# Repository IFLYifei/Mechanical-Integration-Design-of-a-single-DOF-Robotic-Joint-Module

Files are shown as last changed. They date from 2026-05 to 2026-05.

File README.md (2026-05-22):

# Mechanical-Integration-Design-of-a-single-DOF-Robotic-Joint-Module

Mechanical integration design of a single-DOF robotic joint actuator module, including component selection, coaxial packaging, 3D CAD assembly, interface matching, structural verification, and documentation.

## License and Commercial Component Notes

This repository is provided as a personal portfolio and documentation project for the mechanical integration design of a single-DOF robotic joint module.

Commercial components used in the design, including the motor, harmonic reducer, encoder, and driver, are not self-developed components. Product names and model numbers are used only for component identification and compatibility description.

The original SolidWorks files of the motor and harmonic reducer are not included or redistributed in this repository. The encoder and driver models shown in the assembly are simplified envelope models created only according to their basic dimensional information, and are used for layout, space checking, and interface illustration.

These simplified models are not official supplier CAD models and should not be used as manufacturing references.

Unless otherwise stated, the original design documents, drawings, images, and self-designed CAD parts in this repository are created by the author and may be used for reference, modification, manufacturing, or integration into other projects.

No warranty, guarantee of engineering validity, or responsibility for manufacturing results is provided. Users should independently verify dimensions, strength, tolerances, materials, assembly feasibility, and compatibility before any practical application.

## Repository Structure

- `docs/`: Chinese design report
- `drawing/`: assembly and key part drawings
- `images/`: overview, assembly, and exploded-view figures
- `cad/custom-parts/`: self-designed SolidWorks part files
- `cad/simplified-commercial-components/`: simplified envelope models of commercial components

## Project Overview

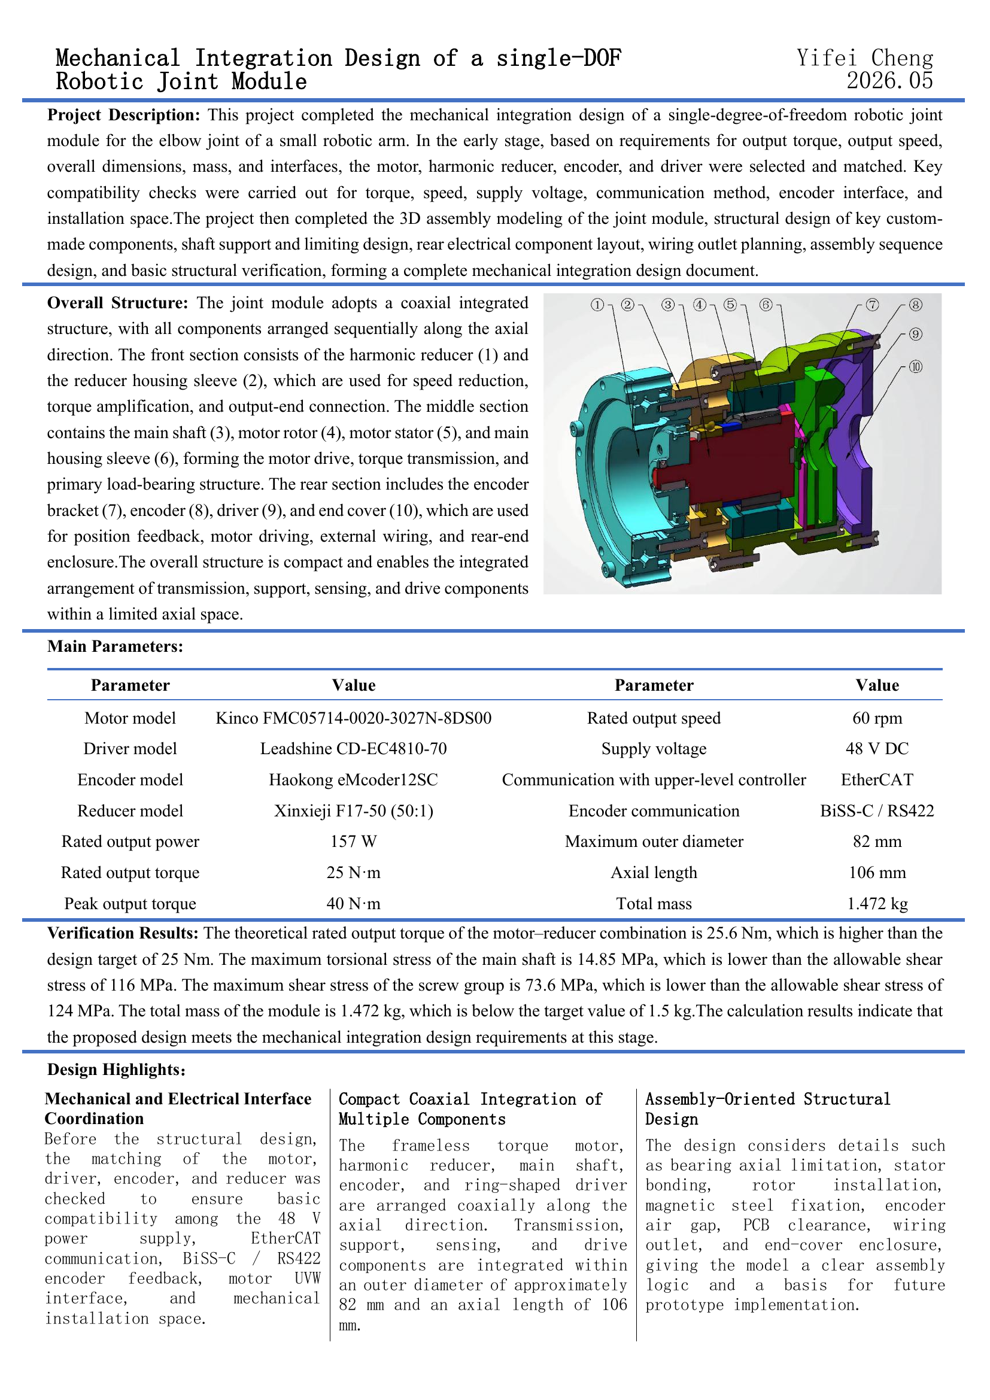
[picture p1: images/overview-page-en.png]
Project Overview


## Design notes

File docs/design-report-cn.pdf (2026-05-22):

# 单自由度机器人关节模组设计说明书

# 程一飞

2026 年 5 月

目录

## 1 项目概述

### 1.1 项目背景

随着协作机器人、小型机械臂和移动机器人等设备的发展，机器人关节模组

逐渐向高集成度、小型化和模块化方向发展。相比传统分散式结构，集成式关节

模组通常需要在有限空间内同时布置电机、减速器、轴承、编码器、驱动器和外

部安装接口，对结构紧凑性、装配可行性和接口布置提出了较高要求。

本项目面向小型机械臂关节应用，设计一种单自由度机器人关节模组。通过

对无框力矩电机、谐波减速器、编码器和驱动器等部件进行集成布置，为后续样

机制造、控制调试和系统应用提供机械结构基础。

### 1.2 项目目标

本项目目标是完成一种单自由度机器人关节模组的机械集成设计，形成结构

紧凑、装配可行、接口明确的关节模组方案。

具体目标包括：完成模组总体结构布局，确定电机、减速器、编码器、驱动

器 PCB 和轴承支撑结构的相对位置；完成关键零部件建模和外购件匹配；设计

外部安装接口、输出接口和内部连接结构；检查主要装配关系、线束空间和结构

干涉问题。

### 1.3 设计内容与项目边界

本项目的设计内容主要包括需求定义、负载扭矩估算、电机与减速器选型匹

配、编码器安装结构设计、定子固定结构设计、转子支撑结构设计、减速器安装

接口设计、输出法兰设计、轴承支撑设计、壳体与端盖设计、线束路径设计、散

热路径设计、机械限位设计以及整机装配结构设计。

项目成果包括三维总成模型、关键零件模型、装配关系、主要接口布置、基

础结构校核、零部件清单和设计说明文件。设计过程中主要关注机械结构集成、

外购件安装兼容性、装配顺序、线束布置空间和后续维护便利性。

本项目不涉及电机电磁设计、减速器内部齿形设计、控制器 PCB 设计、FOC

控制算法开发、EtherCAT 通信协议开发、上位机软件开发和嵌入式固件开发。

电机、减速器、编码器和驱动器均作为外购件处理。本阶段也不进行样机制造、

实验测试，以及完整的热仿真和强度仿真验证。

## 2 设计需求

### 2.1 应用场景

本项目设计的关节模组主要用于小型机械臂的肘关节，实现前臂相对于上臂

的俯仰转动。该位置需要承受前臂、末端执行器及负载产生的弯矩和惯性载荷，

因此对输出转矩、结构刚度和连接可靠性有一定要求。

模组一侧与上臂连杆连接，另一侧与前臂连杆连接，作为机械臂中部的动力

与支撑单元。

### 2.2 主要技术指标

本项目关节模组的主要技术指标如表 2-1 所示。

表 2-1 主要技术指标

指标项目 | 设计目标
关节类型 | 单自由度旋转关节
应用位置 | 小型机械臂肘关节
额定输出转矩 | 25 N·m
峰值输出转矩 | 40 N·m
额定输出转速 | 60 rpm
传动比 | 50:1
供电电压 | 48 V DC
最大外径 | 约 80 mm
轴向长度 | 约 100 mm
整机质量 | 目标不超过 1.5 kg
位置反馈 | 绝对值编码器
编码器通信 | BiSS-C / RS422
上位机通信 | CANopen / EtherCAT

上述指标用于指导电机、减速器、编码器、驱动器及机械结构的选型与集成

设计，后续具体参数以实际外购件和三维模型统计结果为准。

### 2.3 结构设计要求

关节模组应采用同轴集成结构，使电机、减速器、主轴和编码器尽量沿同一

轴线布置，以保证结构紧凑和传动稳定。

壳体结构应能够完成电机定子、减速器、轴承和驱动器 PCB 的安装固定，

并为内部线束预留必要空间。输出端应设置可靠的连接接口，用于与机械臂前臂

连杆连接。

轴系结构应具备明确的轴向定位和径向支撑方式，轴承、挡圈、轴肩和紧固

件布置应满足装配和限位要求。各连接部位应预留合理的螺钉安装空间，避免装

配工具干涉。

整体结构应便于装配和拆卸，关键零部件之间应避免明显干涉，并尽量减少

不必要的复杂结构。

### 2.4 接口设计要求

关节模组应设置清晰的机械接口和电气接口。机械接口包括与上臂连杆连接

的固定接口，以及与前臂连杆连接的输出接口，接口处应具备定位和螺栓连接结

构，保证安装可靠。

电气接口主要包括驱动器电源接口、电机三相 UVW 接口、编码器接口和

上位机通信接口。各接口应布置在便于接线和维护的位置，并避免与轴承、减速

器、壳体和运动部件发生干涉。

接口设计应尽量采用常见规格，便于后续采购、装配和替换。

## 3 总体方案设计

### 3.1 模组总体结构方案

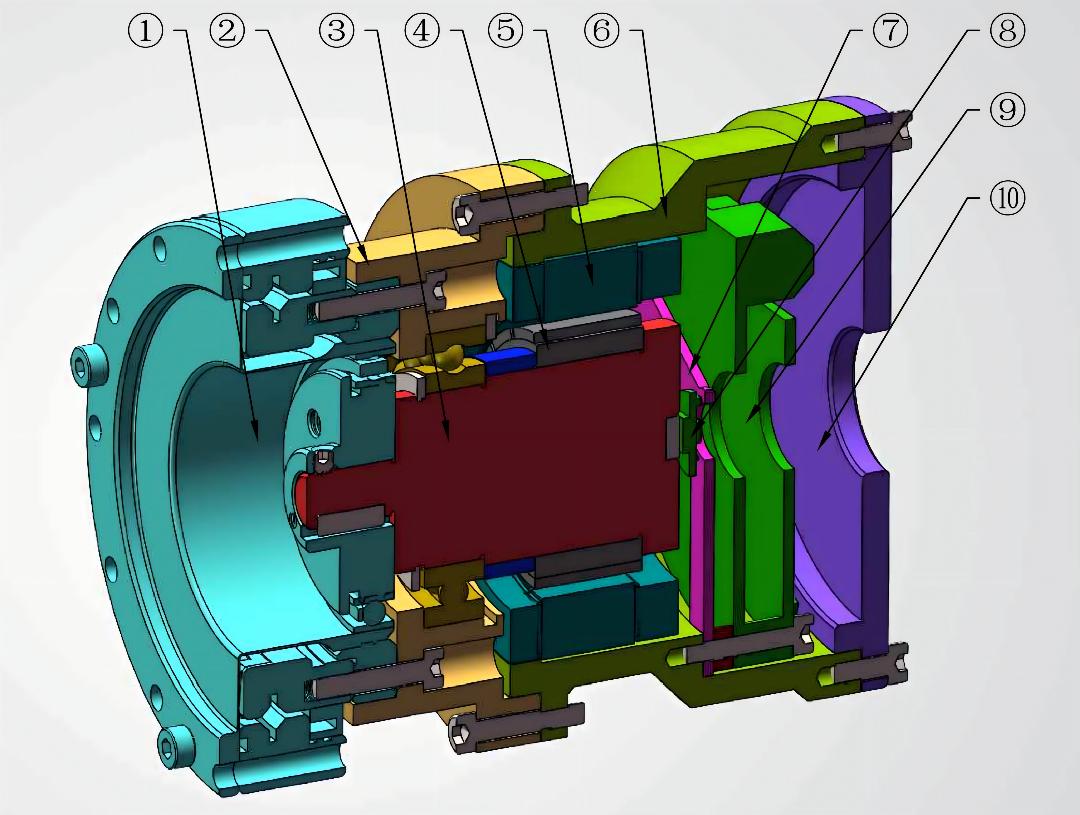
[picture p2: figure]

图 3-1 关节模组总体结构示意图

关节模组采用同轴集成结构，主要由谐波减速器（1）、减速器缸套（2）、

主轴（3）、电机转子（4）、电机定子（5）、主缸套（6）、编码器支架（7）、

编码器（8）、驱动器（9）和端盖（10）组成，如图 3-1 所示。

其中，谐波减速器作为外购传动部件安装在输出侧，减速器缸套和主缸套共

同构成主要承载壳体。电机转子与主轴连接，电机定子固定在主缸套内侧。编码

器通过编码器支架布置在后端，驱动器安装在模组后部空间内，端盖用于封闭和

固定后端结构。整体结构沿轴向紧凑布置，满足肘关节模组的机械集成需求。

### 3.2 传动方案

本模组采用“无框力矩电机 + 谐波减速器”的传动方案。电机定子固定在主

缸套内，电机转子与中心主轴连接，带动谐波减速器的波发生器旋转，作为减速

器的输入端。

谐波减速器由波发生器、柔轮和刚轮组成。本方案中，刚轮与减速器缸套固

定连接，作为固定端；波发生器与电机转子侧轴系连接，作为输入端；柔轮与输

出端连接，作为关节的输出端。电机转矩经波发生器输入后，通过柔轮与刚轮之

间的齿差啮合实现减速增扭，最终由柔轮侧输出至机械臂连杆。

该传动方案传动比大、结构紧凑，适合小型机械臂肘关节对输出转矩和安装

空间的要求。

### 3.3 支撑与定位方案

模组的支撑与定位主要围绕两条传力路径展开。

第一条为外部载荷传递路径。机械臂外部连杆分别与减速器柔轮输出侧接口

和主缸套/端盖后端固定接口连接，外部载荷通过两侧法兰传递至减速器缸套、

主缸套和端盖结构。减速器缸套与主缸套之间采用止口定位和螺栓连接，用于保

证壳体连接刚度和整体同轴性。

第二条为内部转矩传递路径。电机定子固定在主缸套内，电机转子带动主轴

及波发生器旋转，转矩经谐波减速器传递至柔轮输出端。主轴通过轴承支撑在壳

体内，用于承受轴系的径向载荷，并配合轴肩、轴用挡圈和孔用挡圈完成轴向限

位，避免轴承和轴系发生轴向窜动。

该方案通过壳体止口定位、螺栓连接、轴承支撑和挡圈限位，保证外部连接

结构与内部传动轴系具有明确的支撑和定位关系。

### 3.4 电气集成方案

模组后端设置驱动器安装空间，驱动器（9）布置在端盖（10）内侧，用于

连接电机、编码器和外部控制系统。电机三相线由电机定子区域引出后接入驱动

器，对应 UVW 三相接口。

编码器（8）安装在编码器支架（7）上，其信号线和供电线接入驱动器编码

器接口，用于关节位置反馈。驱动器还设置电源接口和通信接口，分别用于外部

48 V 供电和上位机通信。

线束主要集中在模组后端布置，避免穿过减速器输出侧和主要旋转部件区域。

该方案便于接线、维护和后续电气调试。

### 3.5 装配方案概述

模组装配按前端到后端的顺序进行。首先将谐波减速器与减速器缸套连接，

完成输出侧传动部件的初步定位；随后安装主轴、轴承、挡圈及相关轴系零件，

使轴系与减速器输入端建立连接。

之后将主缸套与电机定子组成一体，并与前端减速器缸套连接，完成电机定

子固定和壳体主体装配。电机转子与轴系连接后，形成从电机到谐波减速器的传

动路径。

最后在后端安装编码器支架、编码器、驱动器和端盖，并完成电机线、编码

器线和外部接口的连接。该装配顺序有利于先保证减速器和轴系定位，再完成电

机、电气部件和后端封闭结构的安装。

## 4 关键部件选型

### 4.1 电机选型

根据表 2-1 中的设计目标，关节模组额定输出转矩为 25 N·m，额定输出转

速为 60 rpm，供电电压为 48 V DC，传动比为 50:1。综合考虑转矩、转速、供

电电压和结构集成空间，本项目选用步科 FMC05714-0020-3027N-8DS00 无框

力矩电机作为驱动电机。

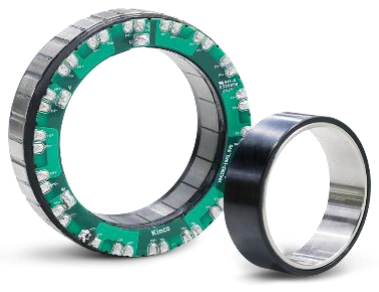
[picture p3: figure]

图 4-1 步科 FMC 系列某款无框力矩电机

按谐波减速器效率 80% 估算，电机侧所需额定转矩为：

Tm =

25
50 × 0.8

= 0.625 N⋅m

所选电机额定转矩为 0.64 N·m，高于计算所需的 0.625 N·m，能够满足额

定输出转矩要求。其额定转速为 3000 rpm，经过 50:1 减速后，理论输出转速

为：

nout =

3000
50 = 60 rpm

该结果与表 2-1 中的额定输出转速目标一致。电机额定功率为 200 W，额

定电压与 48 V 低压驱动系统匹配，适合用于小型机械臂肘关节模组。

所选电机在额定工况下的理论输出转矩为：

Tout = 0.64 × 50 × 0.8 = 25.6N⋅m

因此，该电机能够满足 25 N·m 额定输出转矩目标，并具有一定余量。对于

40 N·m 峰值输出转矩，电机侧所需峰值转矩约为 1 N·m，该工况由电机短时过

载能力和驱动器峰值电流共同承担，后续在 9.2 节中进行匹配校核。

### 4.2 驱动器选型

本项目选用雷赛 CD-EC4810-70 环形伺服驱动器作为电机驱动单元，如图

4-2 所示。该驱动器额定输入电压为 48 V DC ±10%，与本项目 48 V 低压供电

方案一致。

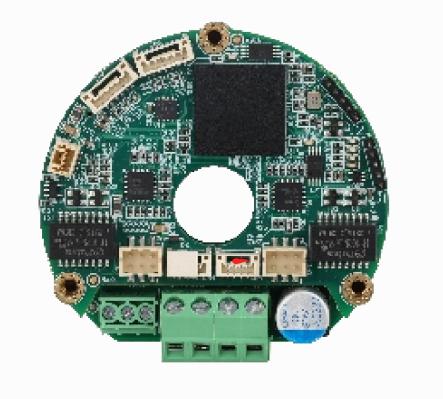
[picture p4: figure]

图 4-2 雷赛 CD-EC4810-70 环形伺服驱动器

该驱动器额定电流为 10 Arms，峰值电流为 30 Arms，连续功率为 256 W。

所选电机额定功率为 200 W，因此驱动器在功率和电流能力上能够满足电机驱

动需求，并具有一定余量。

在接口方面，该驱动器支持伺服电机三相输出、编码器接口和 EtherCAT 通

信接口。其中 EtherCAT 接口满足表 2-1 中对上位机通信方式的要求，可用于

后续与上位机或控制系统进行实时通信。

该驱动器外径为 Φ66 mm，内孔尺寸为 Φ15 mm，整体尺寸适合布置在关节

模组后端空间内，便于实现驱动器与电机、编码器及外部接口的集成。

### 4.3 编码器选型

本项目选用昊控 eMCoder 12SC 微型单圈绝对值编码器作为位置反馈元件，

如图 4-3 所示。该编码器直径为 12 mm，厚度为 2.8 mm，体积较小，适合布

置在关节模组后端有限空间内。

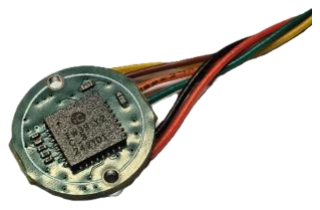
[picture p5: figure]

图 4-3 昊控 eMCoder 12SC 微型绝对值编码器

该编码器供电电压范围为 4.5–5.5 V DC，工作电流约 50 mA，与常见驱动

器编码器供电接口匹配。其单圈分辨率为 24 位，支持 BiSS-C 通信，物理层采

用 RS-422 差分信号，满足本项目对绝对值编码器和 BiSS-C / RS422 通信方式

的要求。

结构安装方面，编码器与磁钢配合使用，推荐磁芯与芯片间距为 0.5 mm，

安装同心度要求为 ±0.2 mm，磁铁水平度要求为 ±2°。因此在结构设计中需通过

编码器支架控制其安装位置和气隙，保证编码器能够稳定读取转子位置信号。

本方案仅采用电机侧编码器进行位置反馈，暂不设置输出端编码器和输出端

力矩传感器。

### 4.4 谐波减速器选型

根据表 2-1 中的设计目标，关节模组传动比为 50:1，额定输出转矩为 25

N·m，峰值输出转矩为 40 N·m。综合考虑输出转矩、结构尺寸和安装形式，本

项目选用鑫械技 F17-50 谐波减速器作为减速传动部件。

该减速器传动比为 50:1，质量约为 0.53 kg，背隙不大于 10 arcsec。根据厂

家参数，F17-50 的平均负载转矩容许最大值为 34 N·m，起动停止时容许峰值转

矩为 44 N·m，瞬间容许最大转矩为 91 N·m，能够满足本项目额定输出转矩和

峰值输出转矩要求。其润滑脂条件下容许平均输入转速为 3500 r/min，能够覆盖

电机 3000 r/min 的额定转速。

本方案中，波发生器作为输入端与电机转子侧轴系连接，刚轮与减速器缸套

固定，柔轮作为输出端与外部连杆连接，实现减速增扭输出。

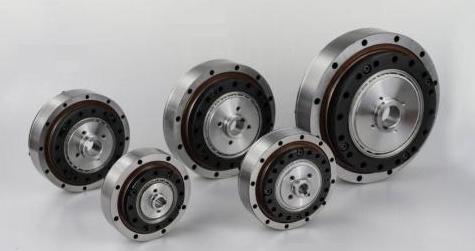
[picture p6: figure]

图 4-4 鑫械技 F 系列谐波减速器

### 4.5 轴承、挡圈与紧固件选型

本项目主轴支撑采用 61905 深沟球轴承。该轴承内径为 25 mm，外径为 42

mm，宽度为 9 mm，尺寸与主轴及减速器缸套轴承孔相匹配。轴承类型按 GB/T

276-2013 深沟球轴承外形尺寸标准选用。

轴向限位采用弹性挡圈结构。主轴上选用轴用弹性挡圈，规格 25，GB/T

894.1；减速器缸套轴承孔内选用孔用弹性挡圈，规格 42，GB/T 893.1。轴承内

圈通过轴肩和轴用挡圈限位，轴承外圈通过减速器缸套台阶和孔用挡圈限位，从

而限制轴系轴向窜动。

紧固件主要采用 GB/T 70.1-2008 内六角圆柱头螺钉。其中，谐波减速器与

减速器缸套连接采用 4 个 M3×16 螺钉；减速器缸套与主缸套连接采用 6 个

M3×16 螺钉；驱动器、编码器支架与主缸套连接采用 3 个 M3×16 螺钉；后端

盖连接采用 4 个 M3×8 螺钉。

输出端辅助固定采用 1 个 M3×3 内六角凹端紧定螺钉，标准为 GB/T

80-2007。主轴与相关连接件之间采用 A 型普通平键 3×3×10，标准为 GB/T

1096-2003，用于传递转矩并保证周向定位。

整体上，轴承、挡圈、螺钉、紧定螺钉和平键均采用常见国标件，便于采购、

装配和后续维护。

## 5 机械结构设计

### 5.1 外壳结构设计

模组外壳主要由减速器缸套、主缸套和端盖组成，如图 5-1 所示。减速器

缸套位于前端，用于安装外购谐波减速器，并对减速器刚轮进行定位和固定；主

缸套位于中部，是电机定子、轴系支撑和后端结构的主要安装基础；端盖位于后

端，用于封闭模组并形成后端连接结构。

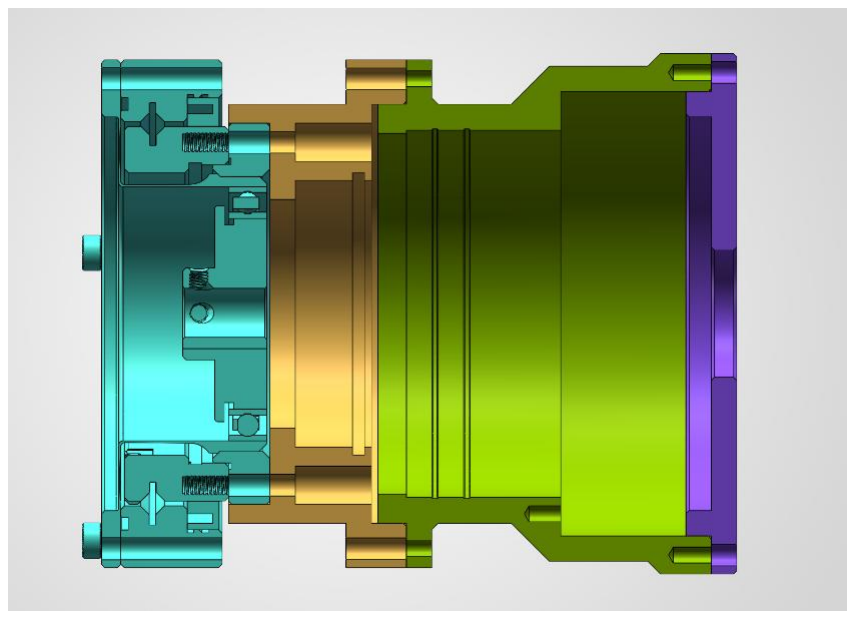
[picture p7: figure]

图 5-1 关节模组外壳结构剖视图

外部机械接口分布在模组左右两侧。左侧为减速器输出侧接口，由谐波减速

器柔轮输出端与前端连接法兰形成，用于连接机械臂前臂连杆；右侧为固定侧接

口，由端盖及主缸套后端法兰形成，用于连接机械臂上臂连杆。左右两侧接口共

同构成肘关节模组与外部连杆的主要连接结构，并承担外部载荷向模组壳体的传

递。

减速器缸套与主缸套之间采用止口定位和螺钉连接，以保证前端减速器与电

机轴系的同轴关系。主缸套内壁设置电机定子安装面，并在定子胶接区域布置两

道环形胶槽，用于储胶和提高定子与壳体之间的连接可靠性。

端盖通过螺钉与主缸套连接，用于固定后端结构并保护内部编码器和驱动器。

整体外壳采用分段式结构，便于减速器、轴系、电机和后端电气部件按顺序装配。

### 5.2 主轴结构设计

主轴结构如图 5-2 所示。该轴贯穿电机转子和谐波减速器输入端，是电机

转矩传递至减速器的主要轴系零件。

在减速器侧，波发生器内部带有减速器自带的柔性轴承，该轴承随波发生器

呈椭圆变形，用于使柔轮产生周期性弹性变形。该部分属于谐波减速器自身结构，

不作为本项目单独设计的支撑轴承。

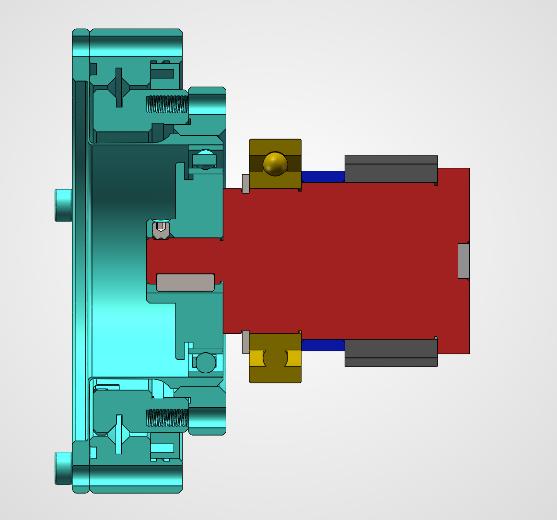
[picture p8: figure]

图 5-2 主轴及轴系结构示意图

在减速器缸套内，另设置一处 61905 深沟球轴承 对主轴进行支撑。轴承内

圈通过轴肩和轴用挡圈限位，轴承外圈通过缸套台阶和孔用挡圈限位，用于保证

轴系的径向支撑和轴向定位。

电机转子安装在主轴中部，采用过盈配合与主轴连接，以传递电机转矩。转

子左侧通过套杯结构定位，右侧通过主轴轴肩定位，从而限制转子轴向位置。

输出端设置 3×3×10 A 型平键 和紧定螺钉，用于输出连接件的周向定位和

辅助固定。整体轴系通过轴承支撑、挡圈限位、过盈配合和键连接，实现电机转

子到谐波减速器的稳定转矩传递。

### 5.3 电机安装结构设计

电机采用无框力矩电机结构，主要由电机定子和电机转子组成，如图 5-3 所

示。电机定子安装在主缸套内侧，通过主缸套内孔进行径向定位，并采用胶接方

式固定。为提高胶接可靠性，主缸套定子安装区域设置两道环形胶槽，用于储胶

并防止装配时胶层被完全挤出。

电机转子安装在主轴中部，通过过盈配合与主轴连接，实现转矩传递。转子

左侧由套杯结构进行轴向定位，右侧由主轴轴肩限位，从而确定转子在轴向上的

安装位置。

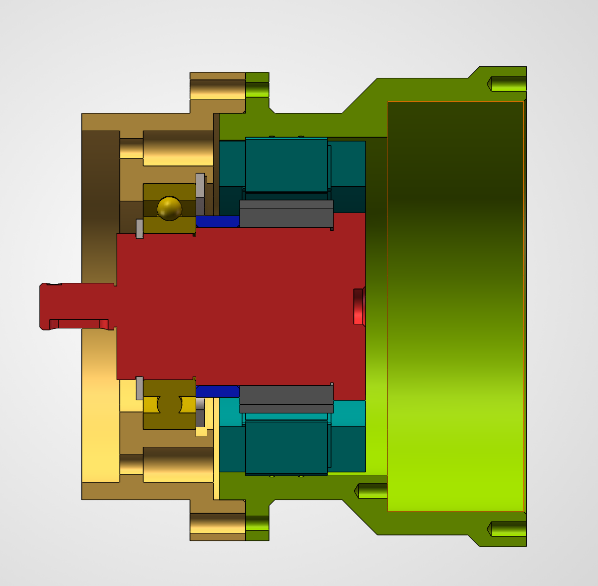
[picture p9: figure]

图 5-3 电机安装结构剖视图

电机整体布置在减速器与后端电气部件之间，定子外侧与主缸套接触，有利

于电机热量通过壳体向外传递。电机引出线从定子区域向后端驱动器方向布置，

避免经过减速器输出侧和主要旋转部件区域。

### 5.4 编码器安装结构设计

编码器安装结构如图 5-4 所示。编码器布置在电机后端，用于检测主轴及

电机转子的角位置信号。磁钢安装在主轴后端，与轴系同步旋转；编码器 PCB 固

定在编码器支架上，并与磁钢保持同轴布置。

编码器支架采用辐条式结构，三端与主缸套固定连接，中间环用于安装编码

器 PCB。该结构能够避开电机转子和后端驱动器空间，同时便于编码器与后端

驱动器的线路布置。

根据编码器安装要求，磁钢与芯片之间需保持约 0.5 mm 的工作气隙。设计

中通过编码器支架的安装面控制轴向距离，并通过主轴后端磁钢安装面保证磁钢

位置。该结构重点保证编码器气隙、同心度和装配可达性。

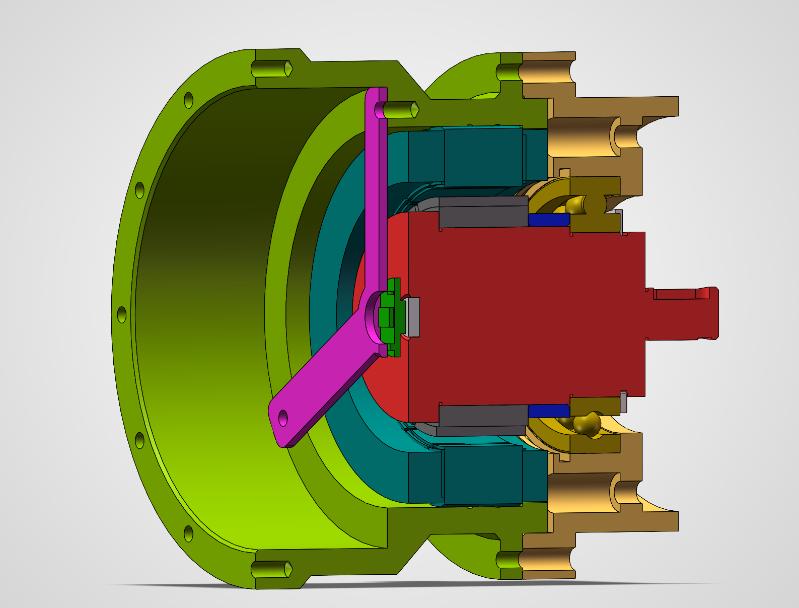
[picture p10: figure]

图 5-4 编码器安装结构示意图

### 5.5 PCB 与电气接口安装结构设计

驱动器 PCB 安装在模组后端空间内，如图 5-5 所示。PCB 通过安装结构

固定在主缸套后侧，并与端盖之间预留装配空间。PCB 中心设有通孔，用于避

让主轴后端和编码器安装区域。

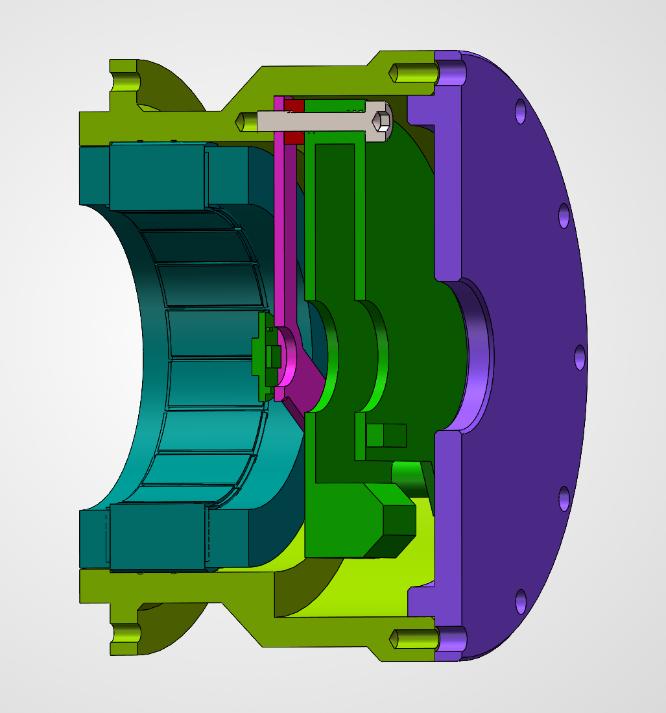
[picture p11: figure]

图 5-5 驱动器 PCB 与电气接口安装结构示意图

编码器支架布置在 PCB 前侧，编码器固定在支架端部，与主轴后端磁钢对

应布置。驱动器 PCB 与编码器支架、主缸套之间保持必要间隙，避免装配干涉。

电气接口集中布置在驱动器 PCB 上，包括电源接口、电机 UVW 接口、

编码器接口和上位机通信接口。端盖中心设置出线孔，用于外部接口线引出。具

体线束走向和空间检查在第 6 章中说明。

## 6 接口与布线设计

### 6.1 电源与通信接口

驱动器 PCB 的主要接口布置如图 6-1 所示。为便于结构建模和后续布线

说明，图中将接口简化为四类：编码器接口（1）、EtherCAT 通信接口（2）、

主回路电源接口（3）和电机 UVW 接口（4）。

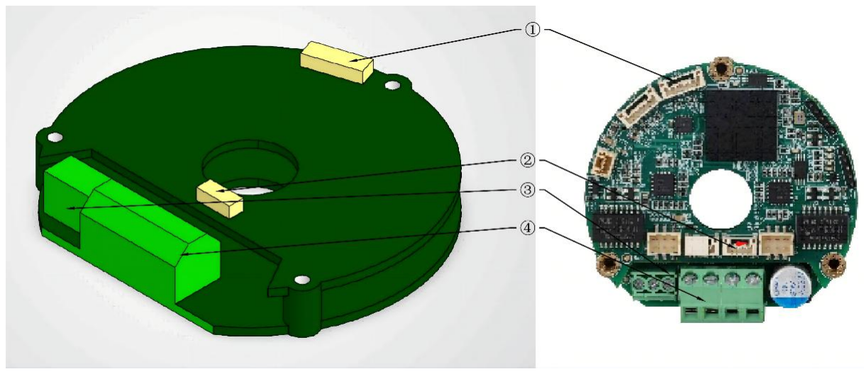
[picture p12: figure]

图 6-1 驱动器 PCB 接口布置示意图

其中，主回路电源接口（3）用于接入外部 48 V DC 电源，为驱动器和电机

驱动部分供电。该接口属于外部接口，设计中通过端盖中心孔引出电源线，与外

部供电系统连接。

EtherCAT 通信接口（2）用于驱动器与上位机或主控制器之间的数据通信，

实现控制指令下发和状态信息反馈。所选驱动器支持 EtherCAT 通信，满足本项

目对上位机通信接口的要求。

编码器接口（1）用于连接 eMCoder 12SC 绝对值编码器，信号形式为

BiSS-C / RS422，同时提供编码器供电。电机 UVW 接口（4）用于连接无框力

矩电机三相绕组。

### 6.2 电机与编码器接口

电机与编码器接口如图 6-2 所示。电机采用三相无框力矩电机，定子绕组

引出 U、V、W 三相线，并接入驱动器 PCB 上的电机 UVW 接口，用于实现

电机驱动。

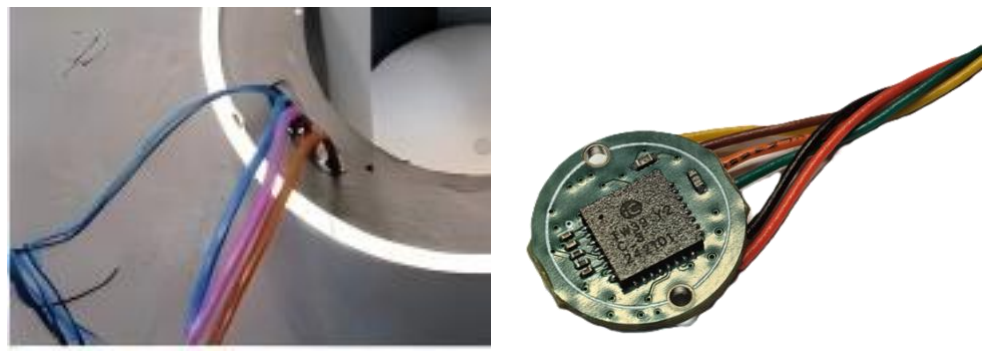
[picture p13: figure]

图 6-2 电机三相线与编码器接口示意图

编码器采用 eMCoder 12SC 单圈绝对值编码器，其引线包括 5 V 供电、0 V

地线、CLK+、CLK−、DATA+、DATA− 等信号线。编码器通过 BiSS-C / RS422

差分信号与驱动器连接，用于反馈电机侧转角位置。

本项目中，电机 UVW 线和编码器线均属于模组内部连接线，主要布置在

电机后端至驱动器 PCB 之间。接口位置集中在驱动器 PCB 附近，便于装配和

后续检查。

### 6.3 线束走向与空间检查

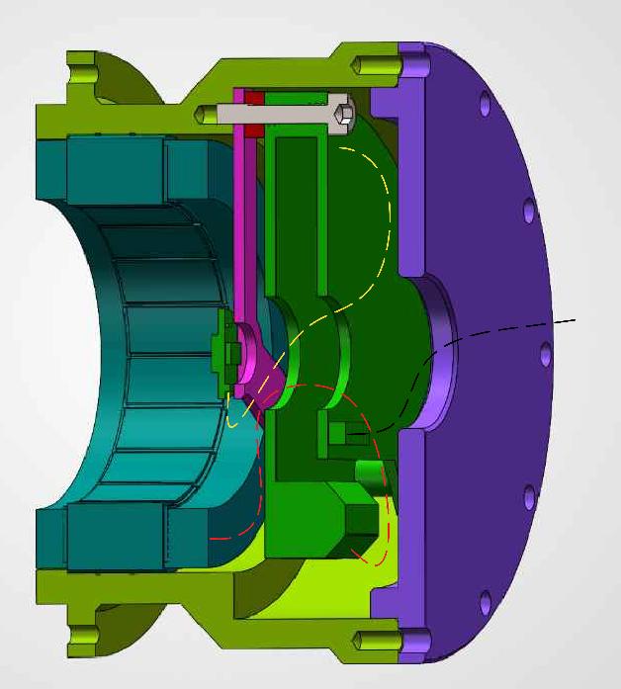
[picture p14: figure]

图 6-3 线束走向与空间检查示意图

线束走向与空间检查如图 6-3 所示。电机 UVW 线和编码器线均布置在模

组后端内部空间内，由编码器支架下方区域引出，并接至驱动器 PCB 相关接口。

驱动器的外部接口线则通过端盖中心孔引出，与外部电源和上位机通信系统连接。

从空间布置看，内部线束主要集中在主缸套后端、编码器支架与驱动器 PCB

之间，未穿过减速器输出侧区域，也不与主要旋转部件直接接触。线束经过区域

与主轴后端、编码器支架和端盖内壁之间均保留一定空间，能够满足基本装配要

求。

由于本项目阶段主要完成机械集成设计，图中线束路径为示意性布置，用于

说明内部连接关系和空间分配。实际布线时还需结合线径、弯曲半径、固定方式

和绝缘保护措施进一步细化。

## 7 装配流程设计

### 7.1 子装配体划分

为便于装配和检查，本项目将关节模组划分为前端减速器组件、轴系组件、

电机定子组件、后端电气组件和端盖组件。

前端减速器组件主要包括外购谐波减速器和减速器缸套，用于完成减速器的

定位与固定。轴系组件主要包括主轴、61905 轴承、轴用挡圈、孔用挡圈、平键、

电机转子和波发生器连接结构，是模组内部转矩传递的核心部分。

电机定子组件由主缸套和电机定子组成，定子通过主缸套内孔定位并采用胶

接固定。后端电气组件包括编码器支架、编码器、驱动器 PCB 及相关接口，用

于完成位置反馈和电机驱动连接。端盖组件用于封闭后端结构，并提供外部连接

接口。

### 7.2 装配顺序

模组装配按前端到后端的顺序进行。首先将外购谐波减速器安装到减速器缸

套内，通过止口定位和螺钉连接完成减速器刚轮固定。

随后装配主轴、61905 轴承、轴用挡圈、孔用挡圈和平键等轴系零件，使主

轴与减速器波发生器建立连接。轴承装入减速器缸套后，通过轴肩和挡圈完成轴

向限位。

第三步安装电机转子。电机转子与主轴采用过盈配合连接，左侧通过套杯结

构定位，右侧通过主轴轴肩限位，保证转子在轴向上的安装位置。

第四步安装主缸套和电机定子。电机定子先固定在主缸套内侧，随后将主缸

套与减速器缸套连接，通过止口和螺钉保证两部分同轴定位。

最后安装编码器支架、编码器、驱动器 PCB 和端盖。编码器与磁钢保持规

定气隙，驱动器 PCB 固定在后端安装位置，完成内部接口连接后安装端盖，完

成模组整体装配。

### 7.3 装配注意事项

装配时应优先保证减速器、主轴、电机转子和电机定子的同轴关系，避免因

装配偏差导致波发生器、轴承或转子受力异常。安装轴承和挡圈时，应确认轴承

端面贴合到位，挡圈完全进入沟槽，避免轴系产生轴向窜动。电机转子与主轴采

用过盈配合安装时，应控制压装方向和受力位置，避免损伤转子、磁钢或主轴。

装配含磁钢部件时应注意强磁吸附作用，避免磁钢吸附螺钉、工具及金属屑

等异物。电机转子装入定子区域时，应防止磁吸力导致转子突然偏移或碰撞定子

内壁，影响电机气隙和转动性能。

定子胶接前应清洁主缸套内孔和定子外圆表面，胶层应连续、均匀，且不得

溢入转子气隙区域。编码器磁钢安装时，应将磁钢可靠胶接于轴尾部端面定位坑

内，并保证磁钢端面与轴线垂直，避免偏斜影响编码器读数。

编码器读头通过直径 1 mm 的定位孔与编码器支架上的定位柱配合安装，

并采用少量结构胶辅助固定。胶接时应避免胶液污染编码器感应面，同时防止编

码器支架受力变形。装配完成后应检查编码器磁钢与读头之间的安装间隙，保证

其满足设计要求且无干涉。

安装驱动器 PCB 和端盖前，应检查内部线束是否被压住，并确认电机相线、

编码器线及驱动器连接线与转子、主轴、螺钉头和锐边之间有足够间隙。线束应

沿预留空间布置并可靠固定，避免装配后受拉、受压或与旋转部件接触。所有螺

钉应按对角或均匀顺序逐步拧紧，避免局部受力过大。

## 8 零部件清单与材料说明

### 8.1 零部件清单

本项目零部件清单与总装配图右下角明细栏保持一致，序号、名称、数量均

按装配图明细表整理，如表 8-1 所示。零部件主要包括自制结构件、外购组件

和标准件三类。

表 8-1 关节模组零部件清单

序号 | 标准号 / 型号 | 名称 | 数量
1 | 鑫械技 F17-50 | 谐波减速器 | 1
2 | GJM-01-01 | 减速器缸套 | 1
3 | GB/T 894.1 | 轴用挡圈 A 型 25 | 1
4 | GB/T 276 | 深沟球轴承 61905 | 1
5 | GB/T 893.1 | 孔用挡圈 A 型 42 | 1
6 | GB/T 70.1 | 内六角圆柱头螺钉 M3×16 | 6
7 | GJM-01-02 | 套杯 | 1
8 | 步科 FMC05714 定子 | 无框力矩电机定子 | 1
9 | 步科 FMC05714 转子 | 无框力矩电机转子 | 1
10 | GJM-01-03 | 驱动器垫圈 | 3
11 | GJM-01-04 | 编码器支架 | 1
12 | GB/T 70.1 | 内六角圆柱头螺钉 M3×16 | 3
13 | GB/T 70.1 | 内六角圆柱头螺钉 M3×8 | 4
14 | 雷赛 CD-EC4810-70 | 关节伺服驱动器 | 1
15 | GJM-01-05 | 端盖 | 1
16 | GJM-01-06 | 主缸套 | 1
17 | 昊控 eMCoder12SC | 绝对值编码器 | 1
18 | GJM-01-07 | 编码器磁钢 | 1
19 | GJM-01-08 | 主轴 | 1
20 | GB/T 70.1 | 内六角圆柱头螺钉 M3×16 | 4
21 | GB/T 80 | 内六角凹端紧定螺钉 M3×3 | 1
22 | GB/T 1096 | A 型平键 3×3×10 | 1

其中，GJM-01 系列为本项目自制结构件编号；电机、减速器、编码器和驱

动器按外购件处理；轴承、挡圈、螺钉、紧定螺钉和平键按标准件处理。该清单

作为后续材料说明、质量属性设置和装配检查的依据。

### 8.2 自制件材料

本项目自制结构件主要包括减速器缸套、主缸套、端盖、套杯、编码器支架、

驱动器垫圈和主轴。材料选择以轻量化、加工性、结构强度和装配需求为依据。

减速器缸套、主缸套、端盖、套杯和编码器支架均采用 6061-T6 铝合金。

该材料密度较低，切削加工性能较好，适合用于关节模组壳体、安装支架和连接

件等结构零件。对于本项目的小型肘关节模组，6061-T6 铝合金能够在保证基本

刚度的同时降低整机质量。

主轴采用 40Cr 调质处理。主轴承担电机转子、轴承和谐波减速器输入端之

间的转矩传递，同时需要保证轴肩、键槽和轴承安装段的强度与耐磨性，因此选

用强度较高的调质钢材料。

驱动器垫圈采用 FR-4 绝缘材料，用于驱动器 PCB 与金属壳体之间的绝缘

和间隔。编码器磁钢采用钕铁硼永磁体，表面镀镍处理，用于配合磁编码器完成

角度检测。

### 8.3 标准件与外购件处理

本项目中的标准件主要包括深沟球轴承、轴用挡圈、孔用挡圈、内六角圆柱

头螺钉、内六角凹端紧定螺钉和平键。标准件均按装配图明细栏中的国标规格选

用，不再进行单独结构设计，只在三维模型中检查其安装空间、装配干涉和连接

位置。

其中，深沟球轴承选用 61905，用于主轴支撑；轴用挡圈选用 A 型 25，

孔用挡圈选用 A 型 42，用于轴承的轴向限位；螺钉主要采用 M3×16 和 M3×8

内六角圆柱头螺钉，用于壳体、端盖、驱动器和编码器支架的连接；输出端采用

M3×3 内六角凹端紧定螺钉 和 3×3×10 A 型平键 进行辅助固定和周向定位。

外购件 主要包 括 F17-50 谐 波减速 器、FMC05714 无框力 矩 电机、

CD-EC4810-70 关节伺服驱动器和 eMCoder12SC 绝对值编码器。这些部件按厂

家提供的外形尺寸、安装接口和主要性能参数进行建模与布置，不对其内部结构

进行设计或修改。设计过程中主要检查外购件与自制结构件之间的安装兼容性、

接口位置和装配空间。

## 9 计算与校核

### 9.1 负载扭矩估算

关节模组用于小型机械臂肘关节，主要承受前臂连杆、末端执行器及负载产

生的重力矩。估算时取连杆长度 L = 0.35m，末端负载质量 mload = 2kg，连杆

质量 mlink = 0.8kg，连杆质心近似位于长度中点，安全系数取S = 1.8。

肘关节最大静态负载扭矩按水平伸展工况估算：

T = S ⋅ g ⋅ (mloadL + mlink

L
2

)

代入参数：

T = 1.8 × 9.81 × (2 × 0.35 + 0.8 ×

0.35
2

) = 14.8N⋅m

计算结果约为 14.8 N·m。考虑到关节启动、制动、加减速和外部扰动等动

态工况，本项目将额定输出转矩目标取为 25 N·m，在静态负载估算值基础上留

有一定余量。

峰值输出转矩用于覆盖短时冲击和加速工况，取 40 N·m。该数值约为额定

输出转矩的 1.6 倍，适合作为小型机械臂肘关节的短时峰值设计目标。

### 9.2 电机与减速器输出能力校核

电机额定转矩为 0.64 N·m，额定转速为 3000 rpm。减速器传动比取 i = 50，

传动效率按 η = 0.8 估算，则电机经减速器后的理论额定输出转矩为：

Tout = Tm ⋅ i ⋅ η = 0.64 × 50 × 0.8 = 25.6N⋅m

计算结果为 25.6 N·m，略高于本项目 25 N·m 的额定输出转矩目标，满足

额定输出要求。

输出转速按电机额定转速和减速比计算：

nout =

nm
i

=

3000
50 = 60 rpm

计算结果为 60 rpm，与设计目标中的额定输出转速一致。

减速器选用 F17-50 谐波减速器。其平均负载转矩容许最大值为 34 N·m，

起动停止时容许峰值转矩为 44 N·m，瞬间容许最大转矩为 91 N·m。因此，减

速器能够满足 25 N·m 额定输出转矩和 40 N·m 峰值输出转矩要求。其润滑脂

条件下容许平均输入转速为 3500 rpm，高于电机额定转速 3000 rpm，输入转速

也满足要求。

综上，电机与减速器组合能够满足本项目的额定输出转矩、额定输出转速和

峰值转矩设计要求。

### 9.3 主轴抗扭强度校核

主轴用于连接电机转子与谐波减速器波发生器，是电机侧转矩传递的主要零

件。校核时以主轴左端端面为坐标原点，沿轴线向右建立 x 轴，如图 9-1 所示。

左端键槽段为转矩输出区，右侧电机转子过盈配合段为转矩输入区。

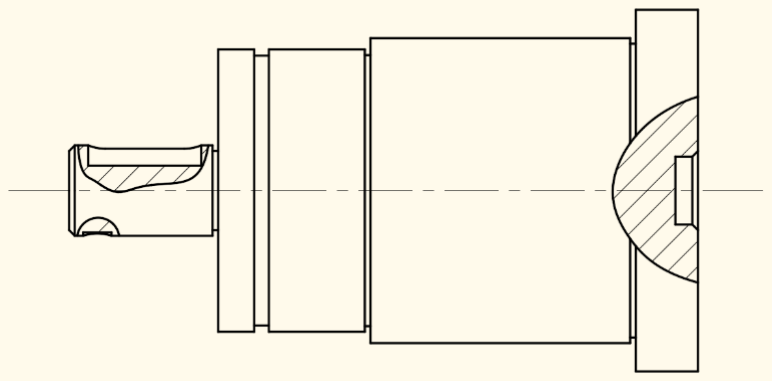
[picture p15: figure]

图 9-1 主轴结构图

本节按峰值输出工况进行主轴抗扭校核。关节峰值输出转矩取 40 N·m，减

速比取 50:1，减速器效率取 0.8，则主轴峰值传递转矩为：

Ts =

40
50 × 0.8

= 1.0N⋅m

在载荷建模中，左端 3×3×10 A 型平键所在区间视为均布输出转矩区域，右

侧电机转子与主轴的 16 mm 过盈配合段视为均布输入转矩区域。因此，主轴内

扭矩沿轴线呈分段变化：在键槽输出区由 0 逐渐增大，在中间传扭区保持最大

值，在转子输入区逐渐减小至 0。

截面强度计算时，主轴按实际阶梯轴结构分段处理。各轴段按对应直径计算

最大扭应力，退刀槽按槽底最小直径计算；键槽段按圆截面扣除矩形键槽后的等

效截面进行近似计算，暂不考虑圆角和局部应力集中系数。该方法可用于判断主

轴在峰值转矩下的危险截面位置和最大扭应力水平。

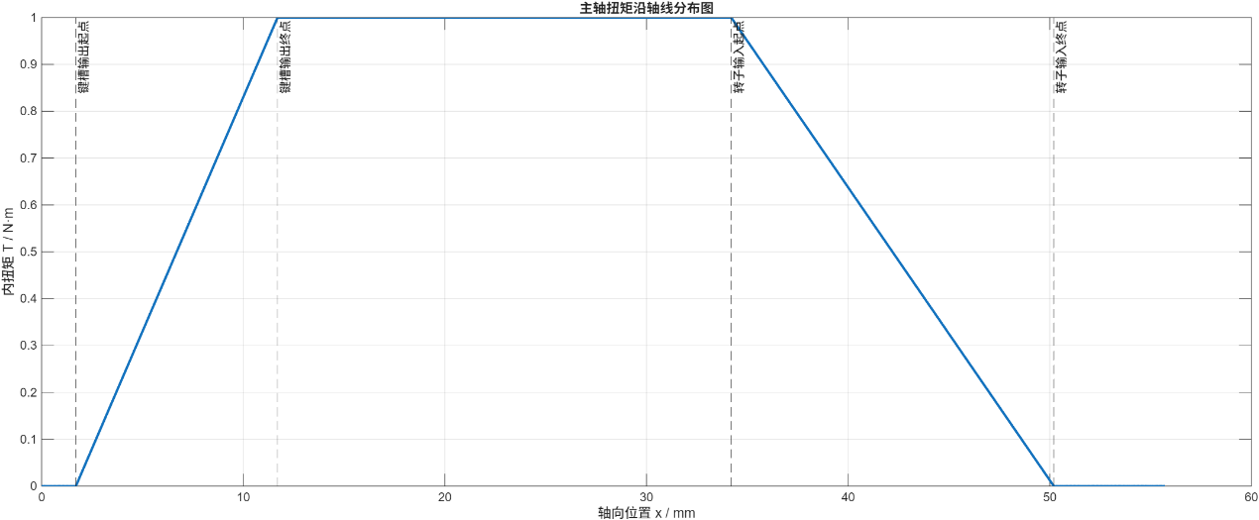
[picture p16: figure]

图 9-2 主轴扭矩沿轴线分布图

由图 9-2 主轴扭矩沿轴线分布图可知，在峰值工况下，主轴内扭矩在左端键

槽输出区由 0 逐渐增大，在中间传扭区达到最大值 1.0 N·m，随后在右侧转子

过盈配合输入区逐渐减小至 0。该结果符合“左端键槽均布输出、右侧转子过盈

段均布输入”的载荷模型。

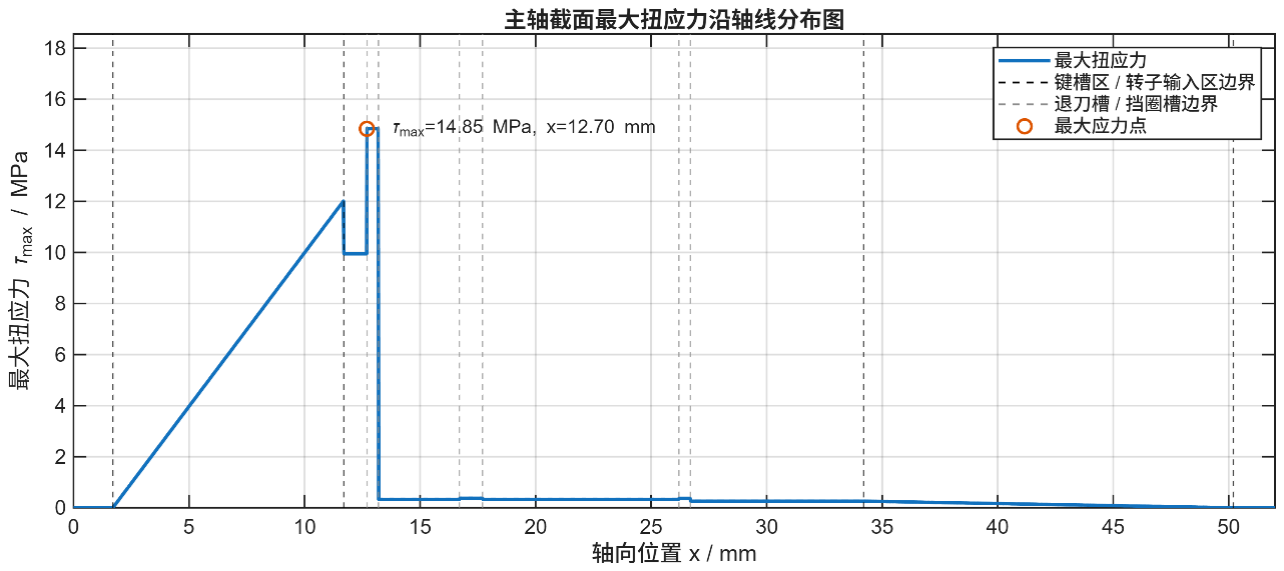
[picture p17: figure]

图 9-3 主轴截面最大扭应力沿轴线分布图

由图 9-3 主轴截面最大扭应力沿轴线分布图可知，最大扭应力出现在 x =

12.70 mm 处，即左端 Φ8 轴段右侧退刀槽位置。该处槽底直径较小，且已接近

完整传递峰值转矩，因此为本次抗扭校核的危险截面。计算得到最大扭应力为：

τmax = 14.85 MPa

主轴材料为 40Cr 调质处理。考虑主轴上存在键槽、退刀槽和轴肩等局部削

弱结构，本次静强度校核取设计安全系数：

ns = 3

40Cr 调质钢的屈服强度按保守值取：

σs = 600 MPa

按剪切屈服准则，材料屈服剪应力近似为：

τs = 0.58σs = 0.58 × 600 = 348 MPa

因此，主轴抗扭许用剪应力为：

[τ] =

τs
ns

=

348
3

= 116 MPa

将计算得到的最大扭应力与许用剪应力比较：

τmax = 14.85 MPa < [τ] = 116 MPa

比较结果表明，主轴在 1.0 N·m 峰值传递转矩作用下满足抗扭静强度要求。

最大应力位置位于左端退刀槽附近，在疲劳校核和结构优化中仍应重点关注该区

域及左端键槽区域。

### 9.4 主轴疲劳强度简化校核

主轴在机械臂肘关节往复运动过程中会承受交变转矩，因此除峰值静强度外，

还需对主轴进行简化疲劳强度校核。本项目暂不进行完整寿命计算，仅按额定工

况下的完全反复扭转载荷进行初步判断。

关节额定输出转矩为 25 N·m，减速比为 50:1，减速器效率取 0.8，则主轴

额定传递转矩为：

Ts,r =

25
50 × 0.8

= 0.625 N⋅m

按完全反复扭转简化处理，主轴平均转矩取 0，转矩幅值取：

Ta = 0.625N⋅m

由 9.3 节可知，在峰值传递转矩 1.0 N·m 下，主轴最大扭应力为 14.85 MPa。

由于扭应力与转矩近似成正比，因此额定交变转矩下的名义交变扭应力为：

τa = 14.85 ×

0.625
1.0

= 9.28 MPa

最大应力位置位于左端退刀槽附近。考虑退刀槽处存在局部应力集中，取疲

劳应力集中系数：

Kf = 1.7

则有效交变扭应力为：

τa,eff = Kfτa = 1.7 × 9.28 = 15.78 MPa

主轴材料为 40Cr 调质钢。其抗拉强度按保守值取：

σb = 800 MPa

材料弯曲疲劳极限近似取：

σ−1 = 0.5σb = 400 MPa

对应扭转疲劳极限近似取：

τ−1 = 0.58σ−1 = 232 MPa

疲劳安全系数为：

nf =

τ−1

τa,eff

=

232
15.78 = 14.7

计算结果表明，主轴在额定交变转矩作用下具有较大的疲劳强度余量，满足

简化疲劳强度要求。由于本次计算未基于实际载荷谱和 S-N 曲线，结果仅作为

初步疲劳判断。

### 9.5 轴承、挡圈与轴系限位校核

本项目主轴支撑采用 61905 深沟球轴承，轴承内径为 25 mm，外径为 42

mm，宽度为 9 mm。主轴轴承安装段直径为 Φ25 mm，减速器缸套轴承孔直径

为 Φ42 mm，与轴承基本尺寸匹配。

轴向限位采用中部轴承固定、两侧不重复固定的方案。轴承内圈由主轴轴肩

和轴用挡圈进行双向限位，轴承外圈由减速器缸套台阶和孔用挡圈进行双向限位，

其限位关系为：

主轴轴肩 → 轴承内圈 ← 轴用挡圈

缸套台阶 → 轴承外圈 ← 孔用挡圈

该方案使 61905 轴承成为主轴的主要定位支承。轴系两端不再设置额外刚

性轴向固定结构，能够避免多处轴向定位造成过定位。电机转子通过过盈配合安

装在主轴上，主要承担转矩传递和自身定位；谐波减速器波发生器内部自带柔性

轴承，主要属于减速器自身工作结构，不作为本轴系的额外固定支承。

从载荷情况看，主轴主要承受电机侧传递转矩，外部关节载荷主要通过谐波

减速器输出端和壳体结构传递。61905 轴承只承担主轴旋转支撑作用，实际径向

力和轴向力均较小。对于该轻载、低速工况，轴承承载能力和寿命均可满足设计

要求。

需要注意的是，挡圈和轴肩用于轴向定位，不应在装配中对轴承形成过大的

轴向压紧。装配后应保证轴承转动顺畅，无明显卡滞和轴向窜动。总体来看，本

方案轴承尺寸匹配，轴向限位明确，且未形成明显过定位，能够满足主轴支撑与

定位要求。

### 9.6 螺钉连接与壳体连接校核

壳体连接主要承受关节输出转矩产生的反力矩。校核时取峰值输出转矩：

Tp = 40N⋅m = 40000 N⋅mm

将各连接处螺钉组简化为均布在同一分布圆上的受力模型，并按保守情况假

设转矩全部由螺钉组承担。单个螺钉承受的等效切向力为：

F =

Tp
n ⋅ r

=

2Tp
nD
其中，n 为螺钉数量，D 为螺钉分布圆直径。

各连接位置的等效切向力计算结果如下：

表 9-1 各位置螺钉受力情况

连接位置 | 螺钉数量 n | 分布圆直径 D / mm | 螺钉切向力 F / N
左侧输出接口 | 4 | 74 | 270
右侧固定接口 | 4 | 76 | 263
减速器缸套与主缸套连接 | 6 | 74 | 180
减速器与减速器缸套连接 | 4 | 54 | 370

由计算结果可知，最不利位置为减速器与减速器缸套连接处，单个螺钉等效

切向力约为 370 N。

螺钉按 M3 内六角圆柱头螺钉 计算，取 M3 螺纹应力截面积：

As = 5.03 mm²

单个螺钉的平均剪应力为：

τb =

F
As
各连接位置剪应力如下：

表 9-2 各位置螺钉剪应力计算结果

连接位置 | 单个螺钉切向力 F / N | 剪应力 τb / MPa
左侧输出接口 | 270 | 53.7
右侧固定接口 | 263 | 52.3
减速器缸套与主缸套连接 | 180 | 35.8
减速器与减速器缸套连接 | 370 | 73.6

最大剪应力为：

τb,max =

370
5.03 = 73.6 MPa

材料按常用 8.8 级钢制螺钉 估算，屈服强度取：

σs = 640 MPa

按剪切屈服准则：

τs = 0.58σs = 0.58 × 640 = 371 MPa

取设计安全系数：

ns = 3

则许用剪应力为：

[τ] =

τs
ns

=

371
3

= 124 MPa

比较可得：

τb,max = 73.6 MPa < [τ] = 124 MPa

在峰值输出转矩 40 N·m 作用下，各连接位置的 M3 螺钉剪切强度满足要

求。其中减速器与减速器缸套连接处受力最大，但仍低于许用剪应力。实际结构

中还存在止口定位和端面接触，螺钉并非单独承担全部载荷，因此该校核结果偏

保守。

### 9.7 关键尺寸链与装配间隙校核

本节仅对影响装配精度和功能实现的关键尺寸链进行检查，重点包括轴系限

位、电机安装、编码器气隙和后端电气件空间。

表 9-3 关键尺寸链与装配间隙检查

校核对象 | 关键尺寸链 | 校核重点 | 结果
主轴轴向 定位 | 主轴轴肩 → 61905 轴承 → 轴用挡圈 / 孔用挡圈 → 减 速器缸套 | 检查轴承是否可靠限位， 轴系是否存在轴向窜动 | 轴承内外圈均有明确限 位，轴系无明显轴向窜 动
电机定转 子安装 | 主缸套内孔 → 电机定子 → 电机转子 → 主轴 | 检查定子胶接位置、转子 过盈配合和定转子间隙 | 定子固定区域明确，转 子定位可靠，定转子无 干涉
编码器气 隙 | 主轴后端磁钢 → 编码器支架 → 编码器 PCB | 检查磁钢与编码器芯片 之间的工作距离 | 按约 0.5 mm 气隙布 置，满足编码器安装要 求
后端电气 空间 | 编码器支架 → 驱动器 PCB → 端盖 | 检查编码器、驱动器和端 盖之间是否干涉 | 后端空间满足安装要 求，端盖闭合后无明显 干涉

其中，编码器气隙是本模组中较敏感的装配尺寸。磁钢安装在主轴后端，编

码器 PCB 固定在编码器支架上，通过支架安装面控制两者之间的轴向距离。若

该距离过大或过小，都会影响编码器信号读取，因此装配时应重点检查该位置。

综合来看，主轴、电机、编码器和后端电气部件的关键尺寸链关系明确，主

要装配间隙满足设计要求。

### 9.8 整机质量估算

整机质量通过 SolidWorks 质量属性功能进行统计。自制件按所设材料密度

计算质量，外购件和标准件按厂家参数、估算值或模型质量进行处理。

根据 SolidWorks 质量属性统计结果，关节模组总质量为：

m = 1.472 kg

该结果小于表 2-1 中整机质量不超过 1.5 kg 的设计目标，满足轻量化要求。

模组质量主要来自谐波减速器、电机定子/转子、减速器缸套、主缸套和端盖等

部件。其中，铝合金壳体结构在保证安装刚度的同时降低了整体质量。

需要说明的是，部分外购件的内部结构模型较为简化，质量属性采用厂家数

据或估算值进行修正，因此该质量结果主要用于方案阶段的整机质量评估。最终

统计结果表明，本关节模组在满足集成结构和输出能力要求的同时，整体质量控

制在目标范围内。

## 10 设计总结

### 10.1 设计结果

本项目完成了单自由度机器人关节模组的机械集成设计。模组面向小型机械

臂肘关节应用，采用无框力矩电机、谐波减速器、绝对值编码器和环形伺服驱动

器的同轴集成方案。

设计内容包括模组总体结构布局、关键零部件建模、外购件选型、轴系支撑

设计、电机安装结构设计、编码器安装结构设计、驱动器 PCB 安装设计、接口

与布线设计、装配流程设计以及基本计算校核。最终形成了三维总装模型、主要

零件模型、装配工程图、零部件清单和设计说明文件。

模组主要参数如表 10-1 所示。

表 10-1 关节模组整机参数表

参数项目 | 参数值
模组类型 | 单自由度旋转关节模组
应用位置 | 小型机械臂肘关节
传动方案 | 无框力矩电机 + 谐波减速器
电机型号 | 步科 FMC05714-0020-3027N-8DS00
驱动器型号 | 雷赛 CD-EC4810-70
编码器型号 | 昊控 eMCoder12SC
减速器型号 | 鑫械技 F17-50
传动比 | 50:1
额定输出转矩 | 25 N·m
峰值输出转矩 | 40 N·m
额定输出转速 | 60 rpm
供电电压 | 48 V DC
上位机通信 | EtherCAT
编码器通信 | BiSS-C / RS422
最大外径 | 82 mm
轴向长度 | 106 mm
整机质量 | 1.472 kg

根据计算与校核结果，模组能够满足 25 N·m 额定输出转矩、40 N·m 峰值

输出转矩和 60 rpm 额定输出转速的设计要求。整机质量为 1.472 kg，低于 1.5

kg 的质量目标，整体方案满足本阶段机械集成设计要求。

### 10.2 方案评价与改进方向

本方案采用无框力矩电机、谐波减速器、绝对值编码器和环形伺服驱动器的

同轴集成结构，整体布置紧凑，主要部件选型明确，机械接口和电气接口较清晰。

减速器、电机、编码器和驱动器均作为外购件处理，降低了设计复杂度，也便于

后续采购和装配。主轴、壳体、轴承、挡圈和螺钉连接等结构经过基本校核，能

够满足本阶段的机械集成设计要求。

当前方案仍存在一定不足。首先，本项目主要完成 CAD 方案和理论校核，

未进行实物加工、装配和实验验证。其次，结构校核以简化计算为主，未进行完

整有限元强度分析、热分析和振动分析。再次，线束固定、防护、密封和散热设

计仍较简化，编码器气隙、转子过盈配合和定子胶接等关键装配环节对实际制造

精度有一定要求。

后续可在现有方案基础上继续优化结构细节，包括完善线束固定与绝缘保护、

增加必要的密封和防护结构、优化壳体减重和散热路径，并进一步校核主轴、壳

体和螺钉连接的强度。若进入样机阶段，还应重点验证电机温升、编码器信号稳

定性、减速器输出精度和整机装配可靠性。

作为个人项目和作品集内容，本项目的价值不只在于完成一个关节模组模型，

更在于完整经历了从需求定义、外购件选型、结构布局、接口协调、装配顺序到

基本校核的设计流程。相比单独绘制某个零件，本项目更强调机械集成能力，需

要在有限空间内同时考虑电机、减速器、编码器、驱动器、轴承、线束和外部接

口之间的相互约束。通过该项目，可以较直观地展示本人对机器人关节模组结构

组成、传动路径、装配逻辑和工程权衡的理解，也为后续继续深入机器人执行器、

机械结构设计和机电一体化集成方向打下了基础。

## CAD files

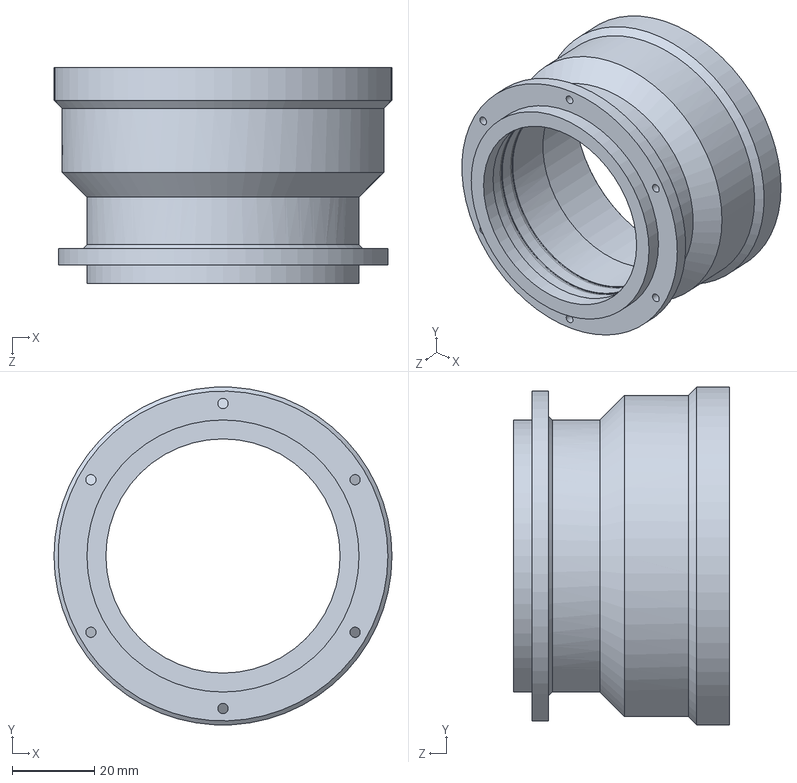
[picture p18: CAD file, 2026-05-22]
cad/custom-parts/main-housing-sleeve.SLDPRT
82.0 x 81.9 x 52.5 mm

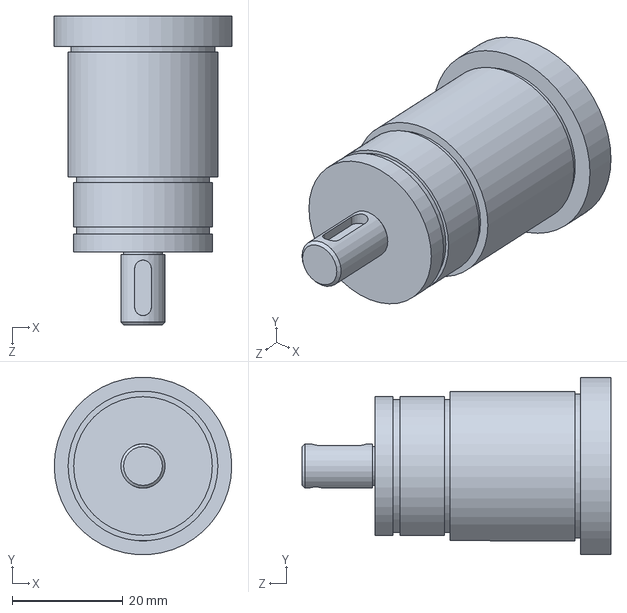
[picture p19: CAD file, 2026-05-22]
cad/custom-parts/main-shaft.SLDPRT
32.0 x 31.9 x 55.7 mm

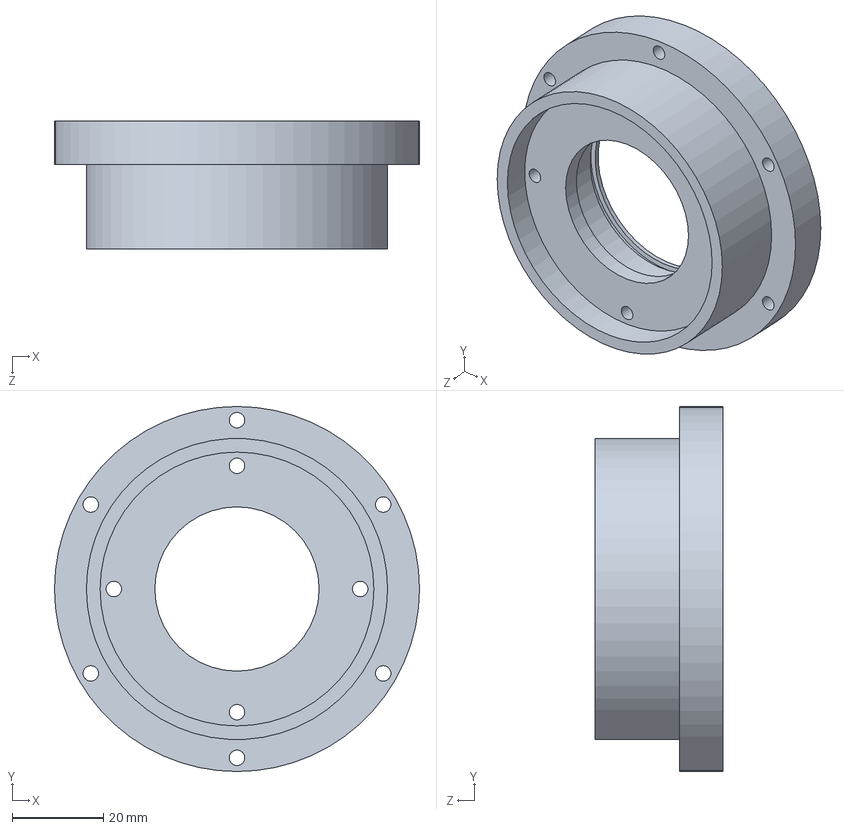
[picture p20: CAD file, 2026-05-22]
cad/custom-parts/reducer-housing-sleeve.SLDPRT
80.0 x 80.0 x 28.0 mm

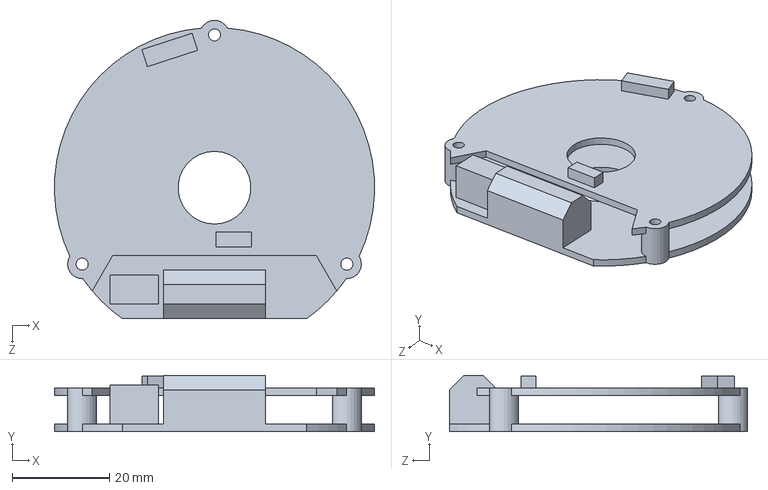
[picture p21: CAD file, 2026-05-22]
cad/simplified-commercial-components/driver-envelope.SLDPRT
66.0 x 11.6 x 61.5 mm

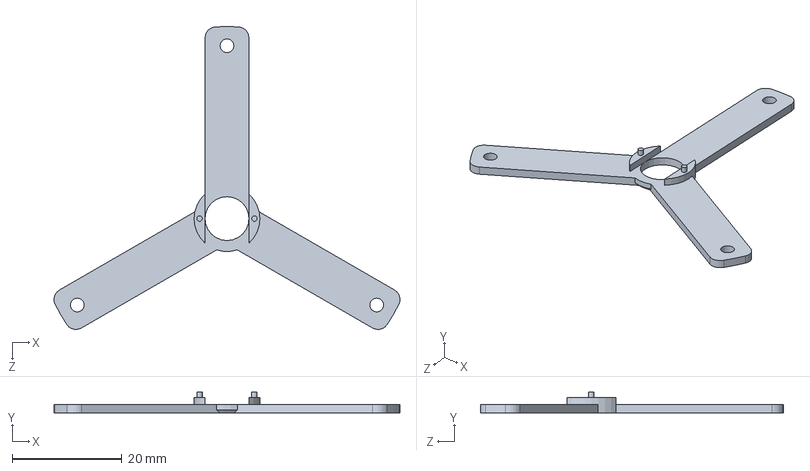
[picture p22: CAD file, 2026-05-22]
cad/custom-parts/encoder-bracket.SLDPRT
63.0 x 3.80 x 55.2 mm

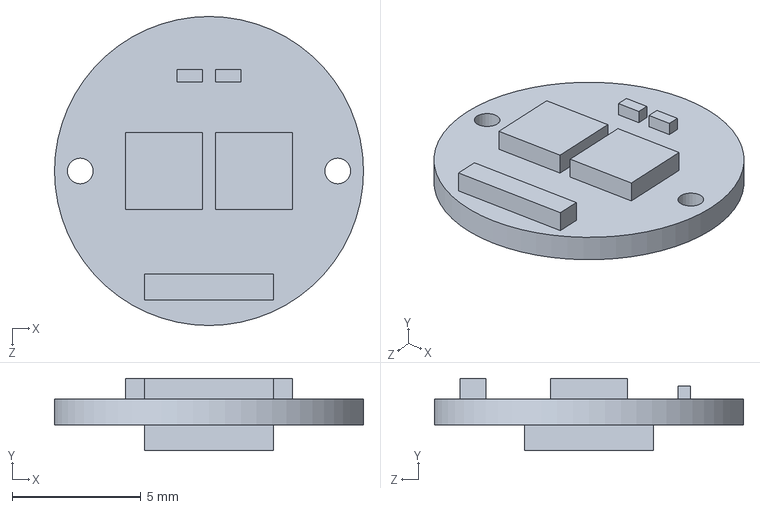
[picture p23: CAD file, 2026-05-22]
cad/simplified-commercial-components/encoder-envelope.SLDPRT
12.0 x 2.80 x 12.0 mm

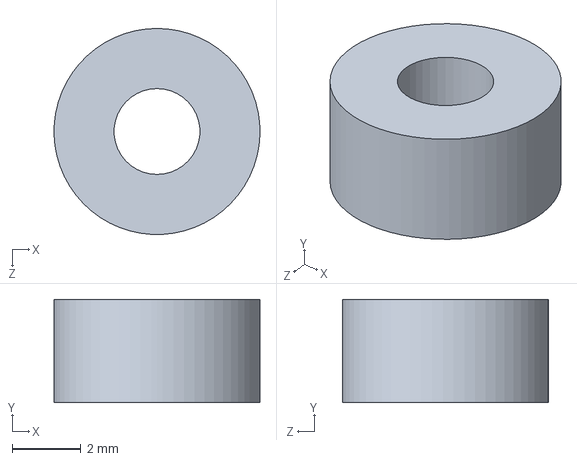
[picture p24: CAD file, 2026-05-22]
cad/custom-parts/driver-spacer-ring.SLDPRT
6.00 x 3.00 x 6.00 mm

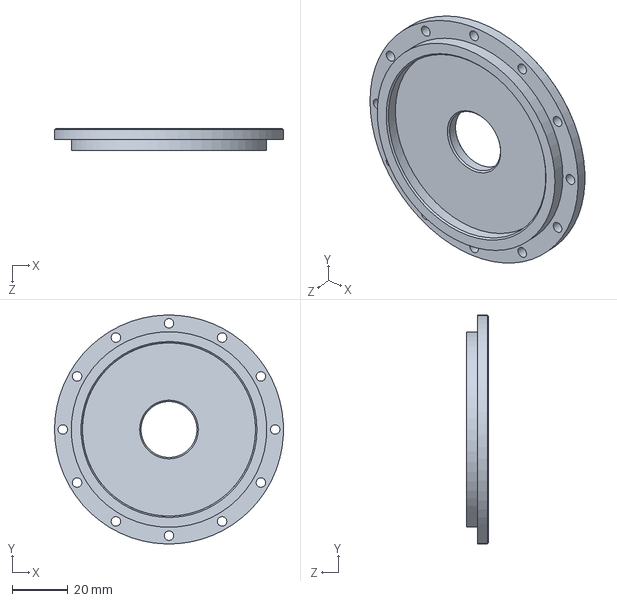
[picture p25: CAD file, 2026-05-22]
cad/custom-parts/end-cover.SLDPRT
82.0 x 82.0 x 8.00 mm

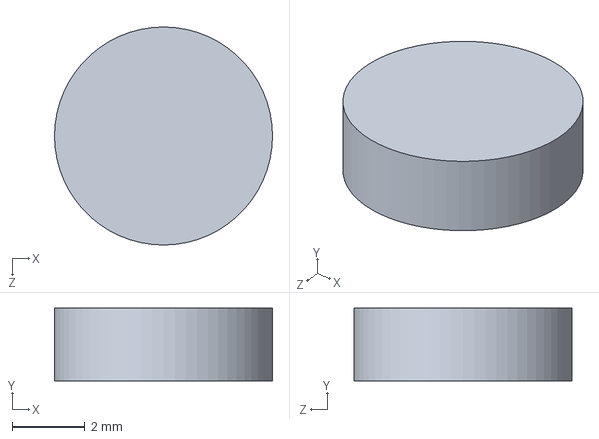
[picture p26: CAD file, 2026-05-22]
cad/custom-parts/encoder-magnet.SLDPRT
6.00 x 2.00 x 6.00 mm

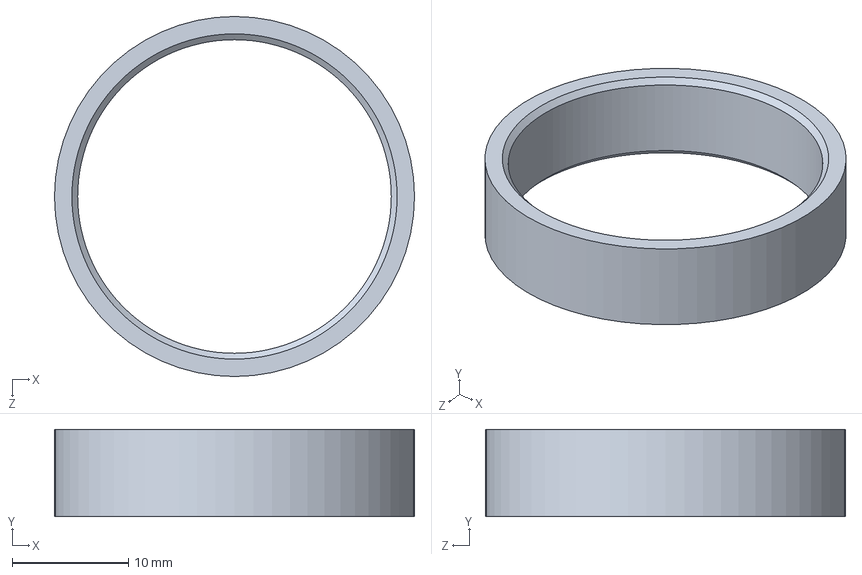
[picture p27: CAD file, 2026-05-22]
cad/custom-parts/cup-sleeve.SLDPRT
31.0 x 7.50 x 31.0 mm

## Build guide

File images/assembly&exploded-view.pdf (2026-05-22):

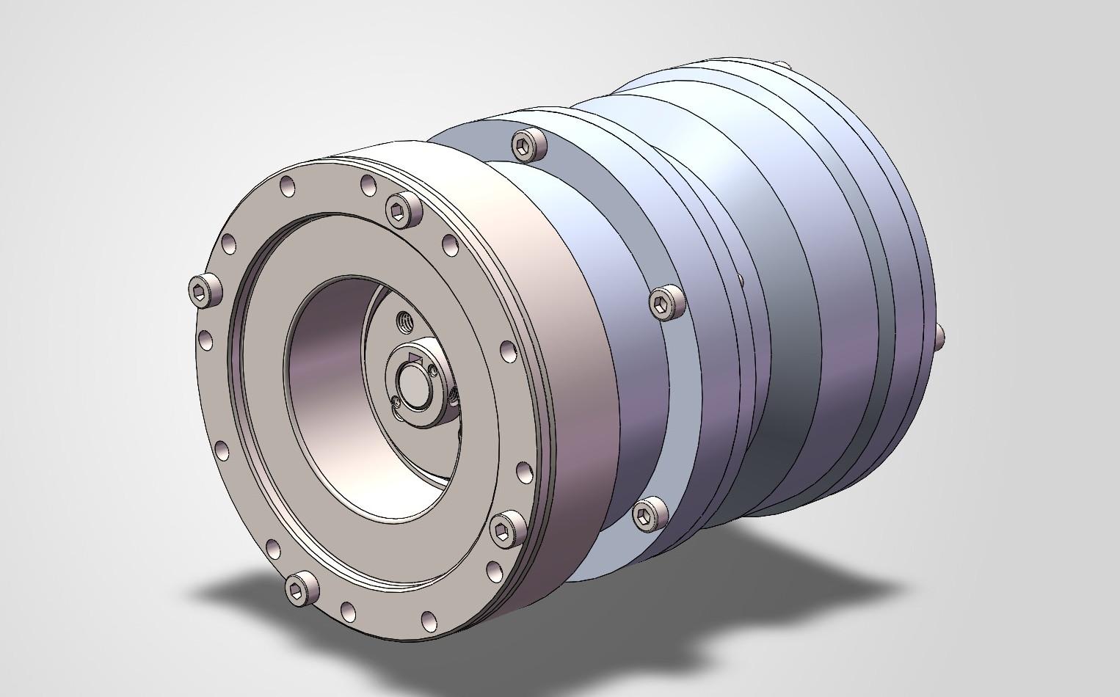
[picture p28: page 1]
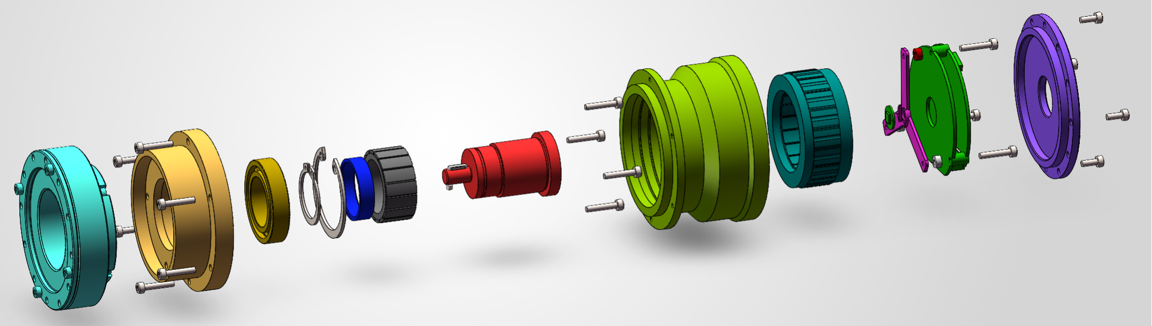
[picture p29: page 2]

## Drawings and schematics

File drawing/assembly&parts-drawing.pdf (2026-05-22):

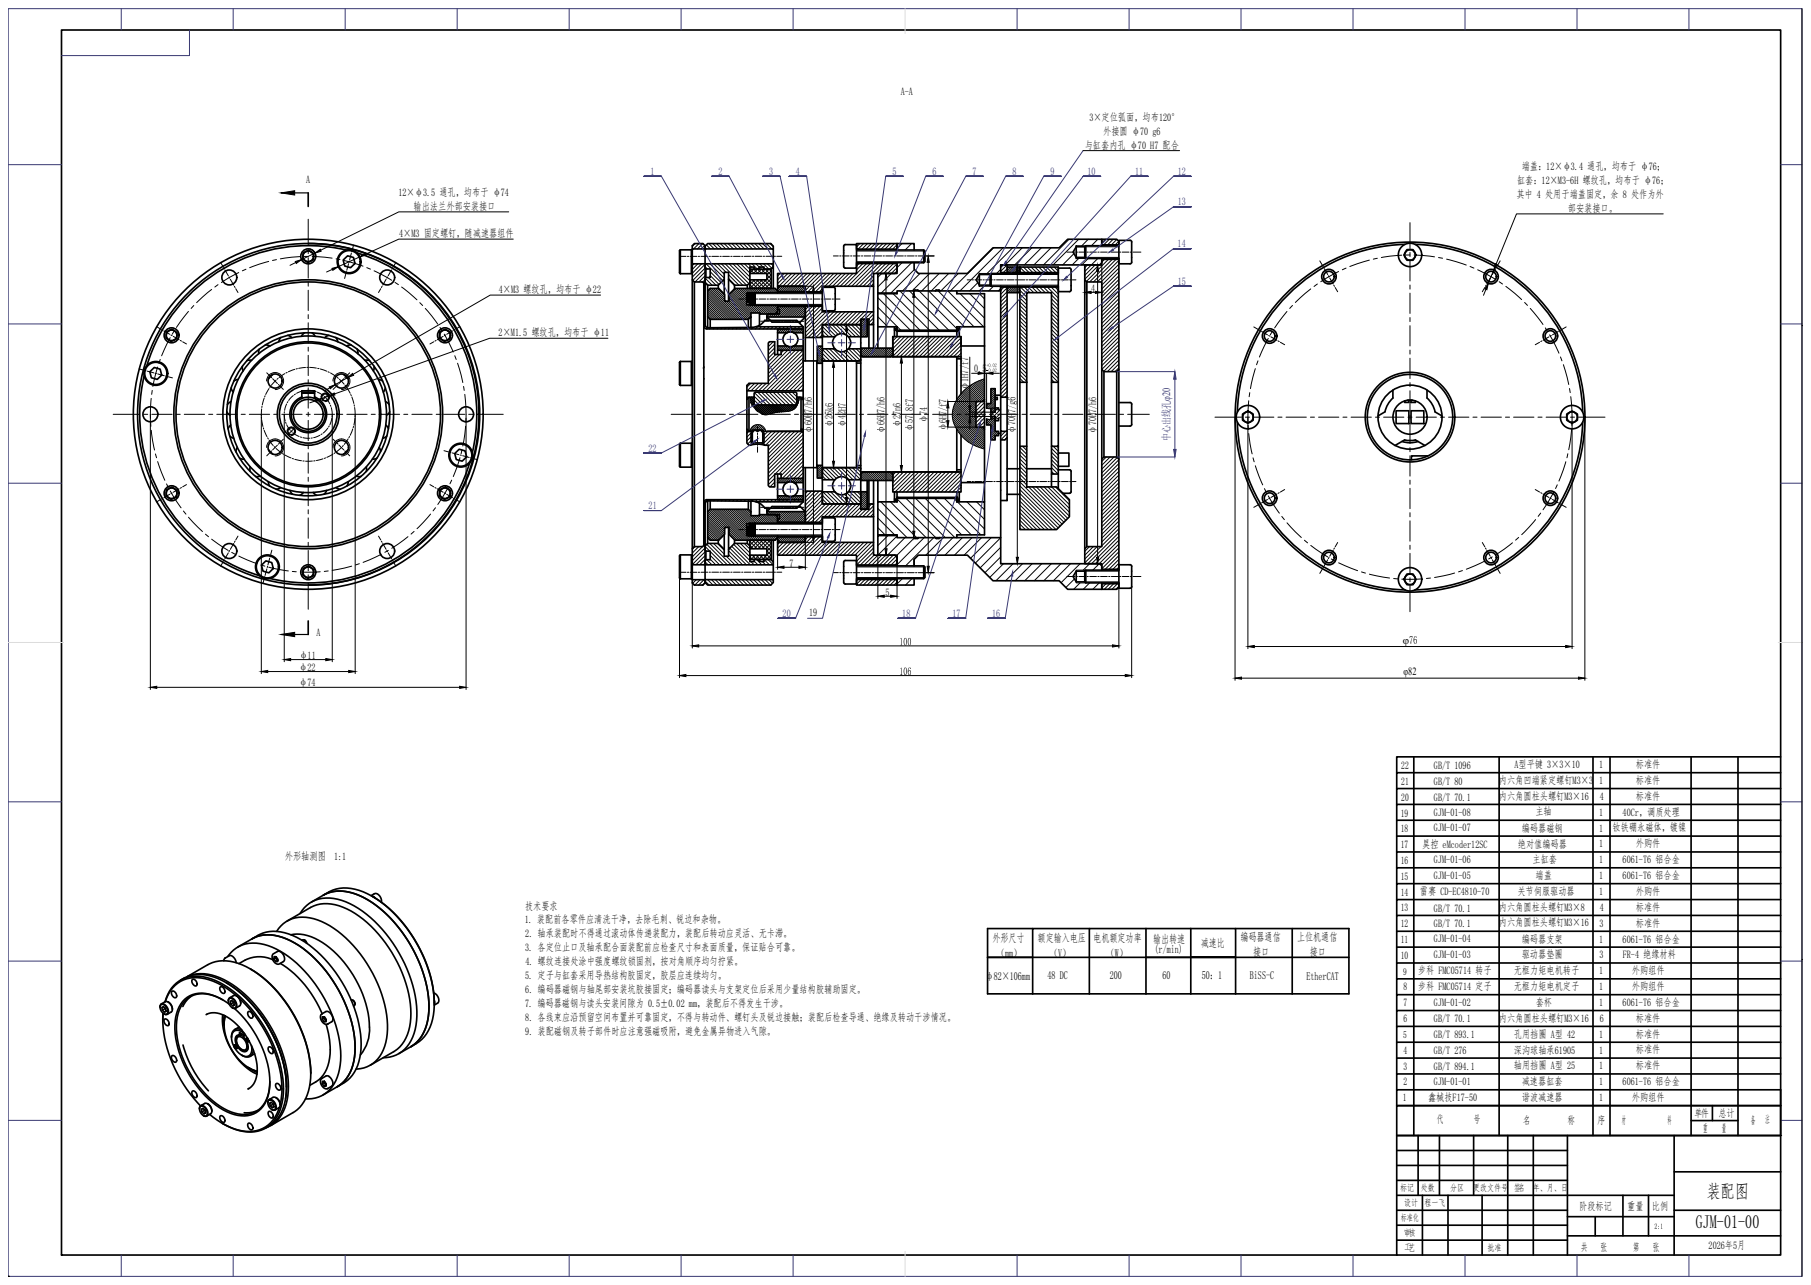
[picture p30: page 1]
GJM-01-00; 标准化; φ82 中心出线孔φ²⁰; 料 ²⁵⁴²; φ⁶H7/f7; 3×定位弧面，均布120° 外接圆 φ70 g6 与缸套内孔 φ70 H7 配合; 部安装接口。; 12×φ3.5 通孔，均布于 φ74 输出法兰外部安装接口; 4×M3 固定螺钉，随减速器组件; 4×M3 螺纹孔，均布于 φ22; 2×M1.5 螺纹孔，均布于 φ11; φ¹H7/f7; 外形轴 11; 鑫械技F17-50; 谐波减速器; 外购组件; 减速器缸套; 6061-T6 铝合金; 轴用挡圈 A型 25; 深沟球轴承61905; 孔用挡圈 A型 42; 内六角圆柱头螺钉M3×16; 标准件; 步科 FMC05714 定子; 无框力矩电机定子; 步科 FMC05714 转子; 无框力矩电机转子; 驱动器垫圈; FR-4 绝缘材料; 编码器支架; 内六角圆柱头螺钉M3×8; 关节伺服驱动器; 外购件; 主缸套; 昊控 eMcoder12SC; 绝对值编码器; 编码器磁钢; 钕铁硼永磁体，镀镍; 40Cr，调质处理; 内六角凹端紧定螺钉M3×3; A型平键 3×3×10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

端盖：12×φ3.4 通孔，均布于 φ76；
缸套：12×M3-6H 螺纹孔，均布于 φ76；
其中 4 处用于端盖固定，余 8 处作为外

技术要求
1. 装配前各零件应清洗干净，去除毛刺、锐边和杂物。
2. 轴承装配时不得通过滚动体传递装配力，装配后转动应灵活、无卡滞。
3. 各定位止口及轴承配合面装配前应检查尺寸和表面质量，保证贴合可靠。
4. 螺纹连接处涂中强度螺纹锁固剂，按对角顺序均匀拧紧。
5. 定子与缸套采用导热结构胶固定，胶层应连续均匀。
6. 编码器磁钢与轴尾部安装坑胶接固定；编码器读头与支架定位后采用少量结构胶辅助固定。
7. 编码器磁钢与读头安装间隙为 0.5±0.02 mm，装配后不得发生干涉。
8. 各线束应沿预留空间布置并可靠固定，不得与转动件、螺钉头及锐边接触；装配后检查导通、绝缘及转动干涉情况。
9. 装配磁钢及转子部件时应注意强磁吸附，避免金属异物进入气隙。

外形尺寸 （mm） | 额定输入电压 （V） | 电机额定功率 （W） | 输出转速 (r/min) | 减速比 | 编码器通信 接口 | 上位机通信 接口

φ82×106mm | 48 DC | 200 | 60 | 50：1 | BiSS-C | EtherCAT

标记 | 处数 | 分区 | 更改文件号 | 签名 | 年、月、日
设计 | 程一飞 | | | | | 阶段标记 | 重量 | 比例

A-A

A

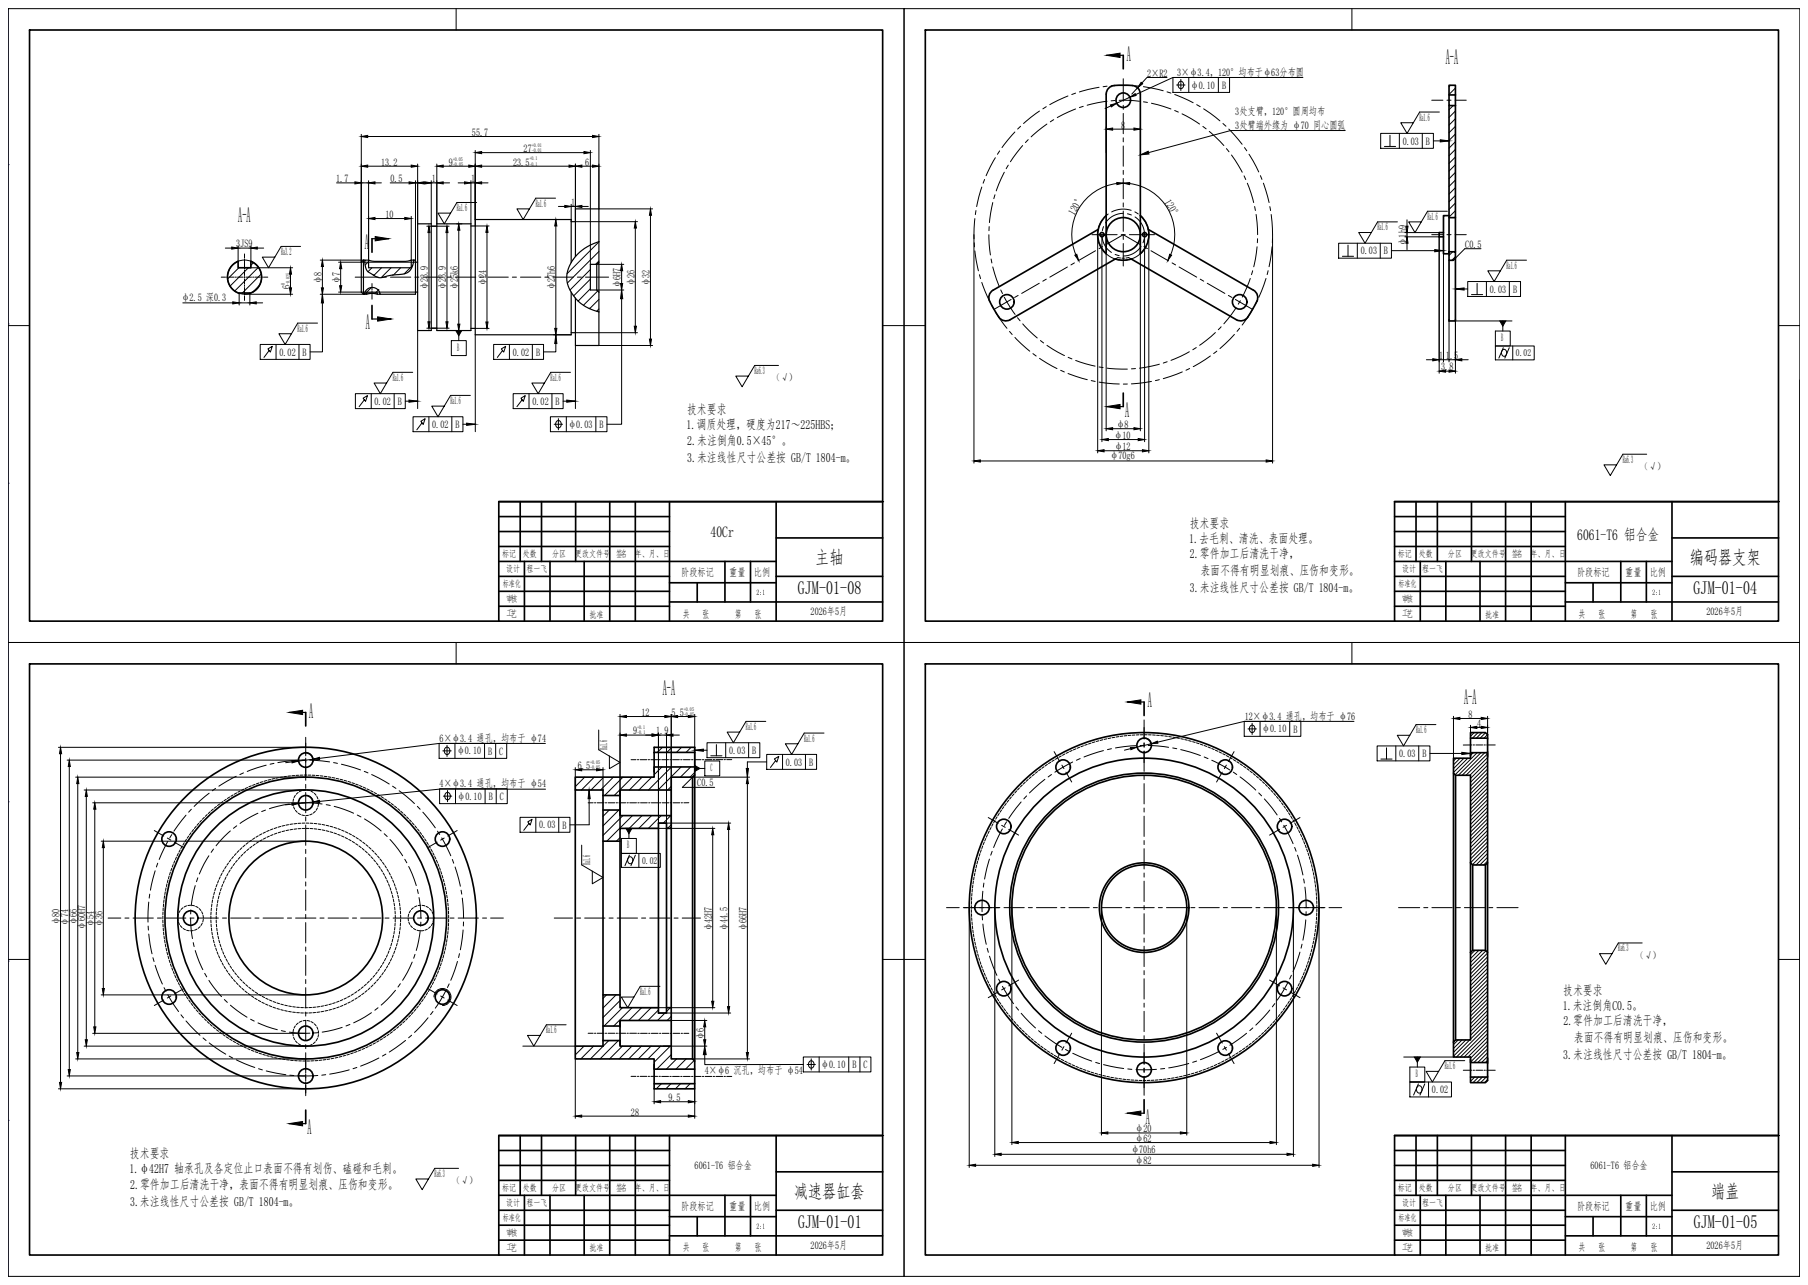
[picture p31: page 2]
φ²⁷h6 φ²⁵k6 φ²³.9; 更改文件号; 程一飞; 阶段标记; 标准化; φ⁶H7; φ²⁶; φ³²; 技术要求 1.调质处理，硬度为217～225HBS； 2.未注倒角0.5×45°。 3.未注线性尺寸公差按 GB/T 1804-m。; 6061-T6 铝合金; 6×φ3.4 通孔，均布于 φ74; 4×φ3.4 通孔，均布于 φ54; φ6 4×φ6 沉孔，均布于 φ54; 12×φ3.4 通孔，均布于 φ76; 技术要求 1.未注倒角C0.5。 2.零件加工后清洗干净， 表面不得有明显划痕、压伤和变形。 3.未注线性尺寸公差按 GB/T 1804-m。; 2×R2 3×φ3.4，120°均布于φ63分布圆; 3处支臂，120°圆周均布 3处臂端外缘为 φ70 同心圆弧

技术要求
1.去毛刺、清洗、表面处理。
2.零件加工后清洗干净，
表面不得有明显划痕、压伤和变形。
3.未注线性尺寸公差按 GB/T 1804-m。

1.φ42H7 轴承孔及各定位止口表面不得有划伤、磕碰和毛刺。
2.零件加工后清洗干净，表面不得有明显划痕、压伤和变形。

A

A-A

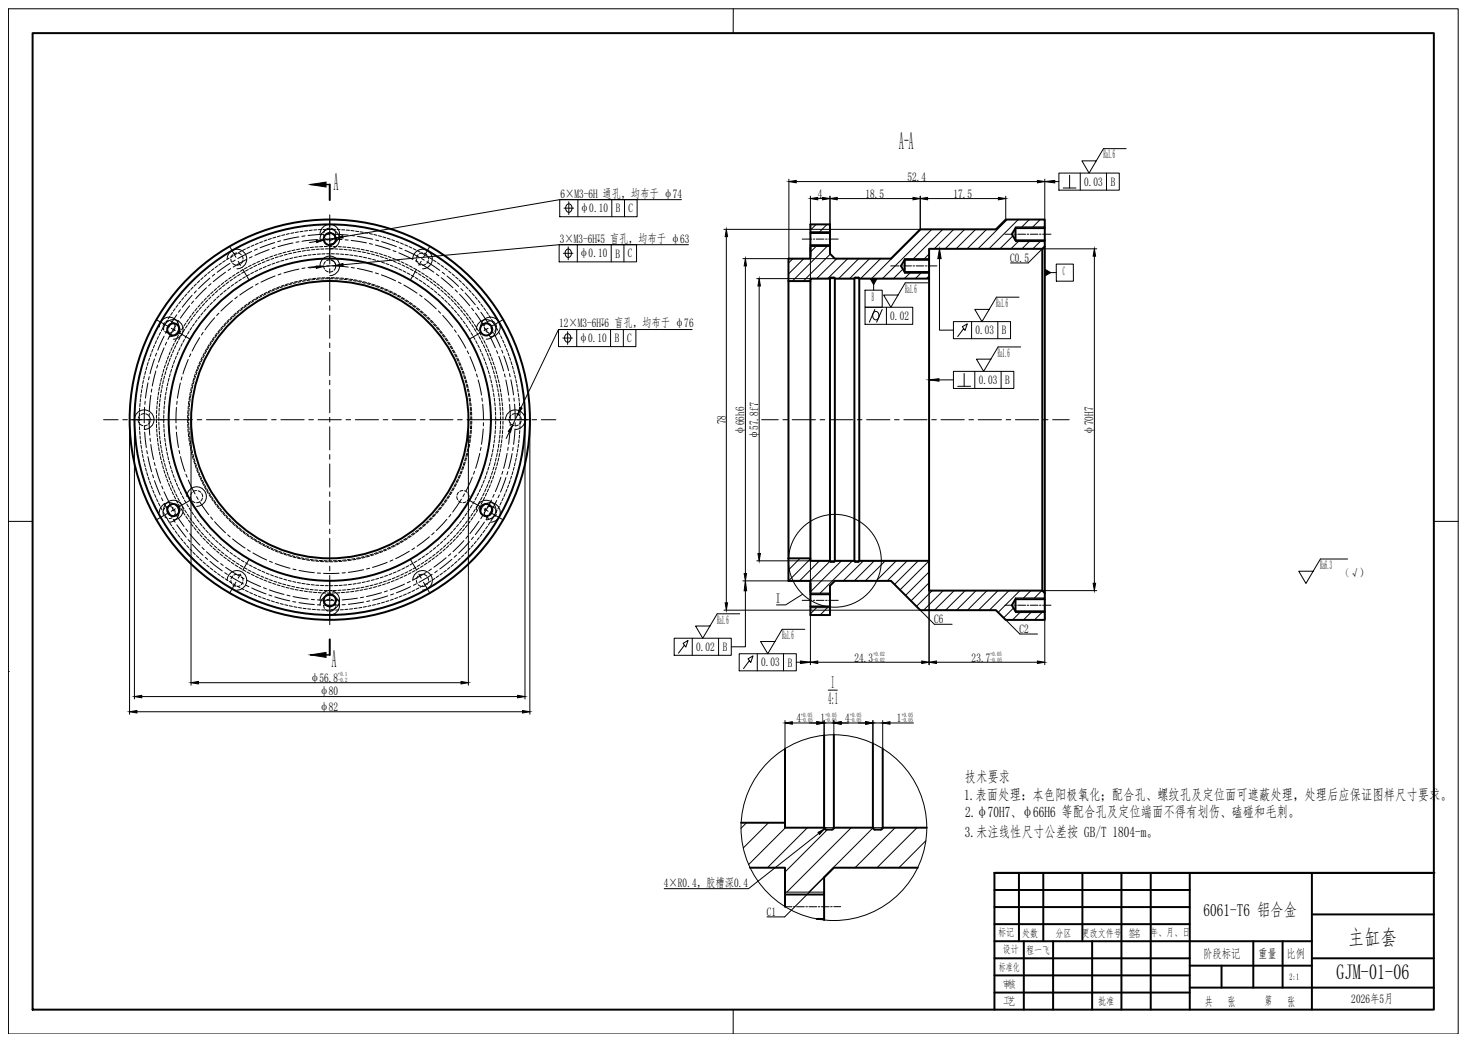
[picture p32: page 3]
6061-T6 铝合金; 6×M3-6H 通孔，均布于 φ74; 12×M3-6H↧6 盲孔，均布于 φ76; 3×M3-6H↧5 盲孔，均布于 φ63; 4×R0.4，胶槽深0.4

技术要求
1.表面处理：本色阳极氧化；配合孔、螺纹孔及定位面可遮蔽处理，处理后应保证图样尺寸要求。
2.φ70H7、φ66H6 等配合孔及定位端面不得有划伤、磕碰和毛刺。
3.未注线性尺寸公差按 GB/T 1804-m。

标记 | 处数 | 分区 | 更改文件号 | 签名 | 年、月、日
设计 | 程一飞 | | | | | 阶段标记 | 重量 | 比例
标准化
审核
